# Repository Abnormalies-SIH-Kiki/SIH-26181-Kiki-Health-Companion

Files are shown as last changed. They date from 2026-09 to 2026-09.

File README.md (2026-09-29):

# Kiki - Your AI Health Companion

**SIH 2026 · PS 26181 · Hardware · MedTech / BioTech / HealthTech**

  

Kiki lives on your desk, learns your routines, and talks to you like a friend who actually remembers things[^memory]. Step outside and the same Kiki comes with you, on your wrist.

* **Looks after you** – medicines, schedule, heart rate, sleep.
* **Keeps you in the loop** – reads your WhatsApp, replies for you, brings you news worth hearing.
* **Your yoga instructor** – it watches through the camera, so "I did it" doesn't count.
* **Actually good company** – memory, personality, a bit of humour.

One Kiki across your desk, wrist, and phone — keeping your heart rate, sleep, falls, and surroundings in one place.

## Table of Contents

- [Project Information](#project-information)
- [Problem Statement](#problem-statement)
- [Proposed Solution](#proposed-solution)
- [Key Features](#key-features-mapped-to-problem-statement)
- [Impact](#impact)
- [Hardware and Software](#hardware-and-software)
- [Architecture](#architecture)
- [Run It](#run-it)
- [Code and Build Files](#code-and-build-files)
- [What's Left](#whats-left)
- [Future Scope](#future-scope)

---
<p align="center">
  <h3>✨ 🌟 Kiki Health Companion — Demo Video 🌟 ✨</h3>
  <a href="https://www.youtube.com/watch?v=SXq7fLjbRYM" target="_blank">
    
  </a>
  <br /><br />
  <a href="submission/SIH26181_Team_Abnormalies_Presentation.pdf">
    
  </a>
  <a href="https://drive.google.com/file/d/19Gz7P0E8064CH7wUCHbpV1ZqjmQZaEzY/view" target="_blank">
    
  </a>
</p>

## Project Information

- **Project Title:** Kiki Health Companion
- **PS ID:** 26181
- **PS Title:** A secure, AI-powered Personal Health Companion that delivers real-time, privacy-preserving health monitoring and early warning capabilities, helping individuals recognize health risks before they become emergencies. The solution should improve resilience during heat waves, floods, pollution events, and other disasters common in India while enabling continuous health support through on-device intelligence.
- **Category:** Hardware
- **Theme:** MedTech / BioTech / HealthTech
- **Team:**  Team Abnormalies, NSUT
  - Suyash Srivastava — Hardware & CAD Design
  - Vaibhav Arora — Systems Architecture, AI & Voice Pipeline
  - Aditi Sharma — Backend Engineering & Database 
  - Chirag Goel — Technical Research, Pitch & Video Production
  - Aniket Sharma — Frontend Development & UI/UX Lead 
  - Aavya — Documentation, Web UI & Testing

## Problem Statement

India faces recurring health crises during heat waves, floods, pollution events, and disease outbreaks. Vulnerable groups — elderly, outdoor workers, chronic patients — lack continuous health monitoring that works offline. The problem demands a secure, AI-powered Personal Health Companion that:

* **Talks like it cares** — multilingual, voice-first, for people who won't open an app and can't always read one. A smartwatch hands you numbers and walks away; Kiki answers in about a second, remembers you, and asks how you're doing.
* **Monitors heart rate, SpO₂, activity, sleep, and environmental conditions**
* **Detects anomalies on-device** (heat stress, dehydration, falls, respiratory distress)
* **Provides actionable alerts and emergency assistance**

Kiki directly addresses all of these.

## Proposed Solution

Kiki is a desktop companion and a wearable built around the same idea. The desktop stays in the room and handles conversation, reminders, measures ambient temperature/pressure and camera-based activity checks. The wearable goes with the person and handles steps, on-demand heart rate, and possible falls.

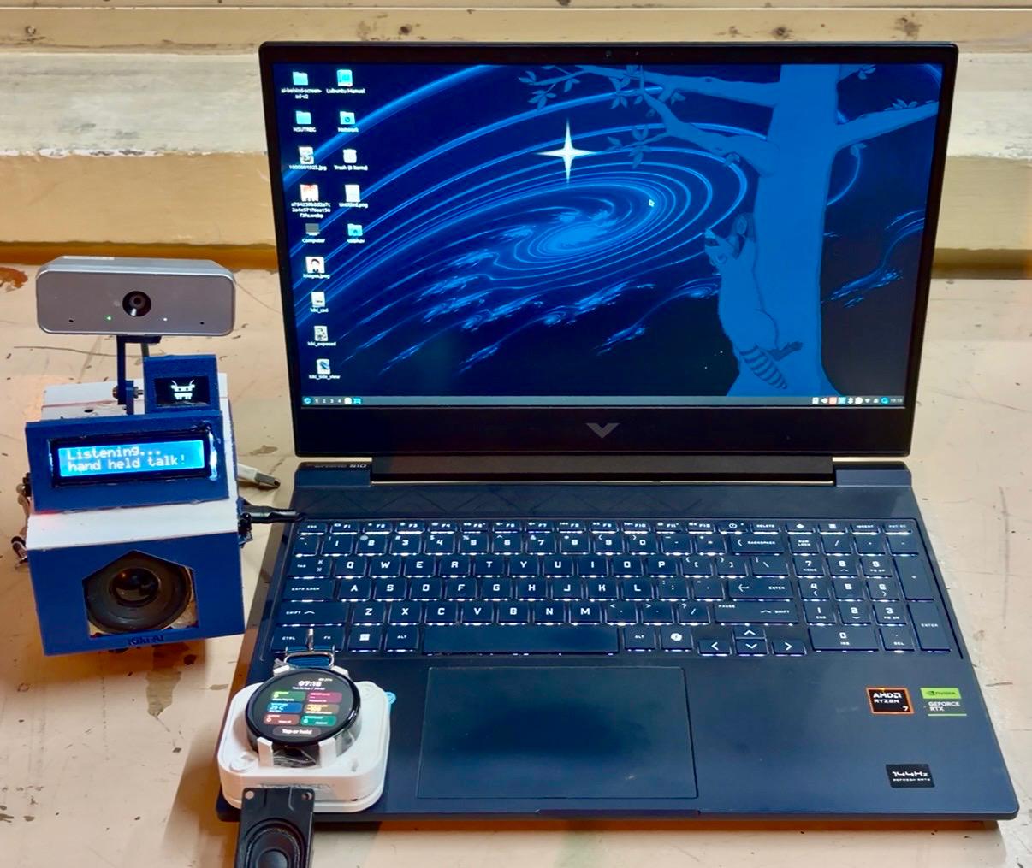
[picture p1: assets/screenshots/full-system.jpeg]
Desktop and wearable health companion and laptop


A health reminder is more useful when it fits the person's day. Kiki keeps routines and recent observations together, so someone can talk through a reminder or an exercise instead of working through an app. Voice interaction supports English and Hindi.

The desktop has a camera for activity detection, face recognition, and exercise checks. The wearable uses wrist motion, with fall detection running in firmware. If it detects a possible fall, it gives the wearer time to respond before requesting a family alert through the gateway.

Both devices use a laptop for speech recognition, speech generation, and the local conversation model. Some reasoning runs through cloud services. Local speech processing and firmware fall detection don't need internet, but the devices still need access to the laptop for conversation. Weather updates, cloud agents, and WhatsApp/email alerts need connectivity.

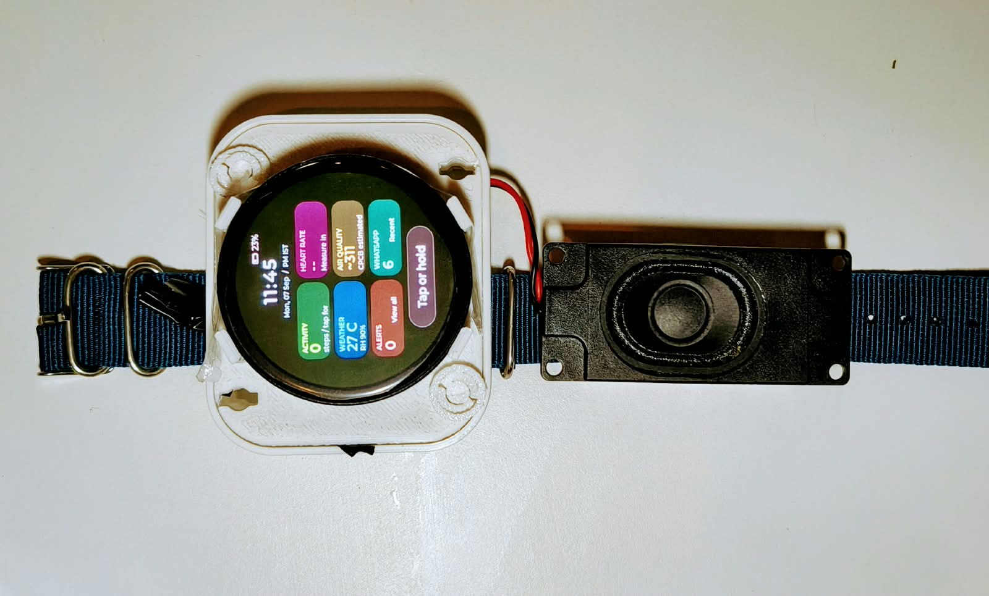
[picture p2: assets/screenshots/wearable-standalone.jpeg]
Real prototype - wearable

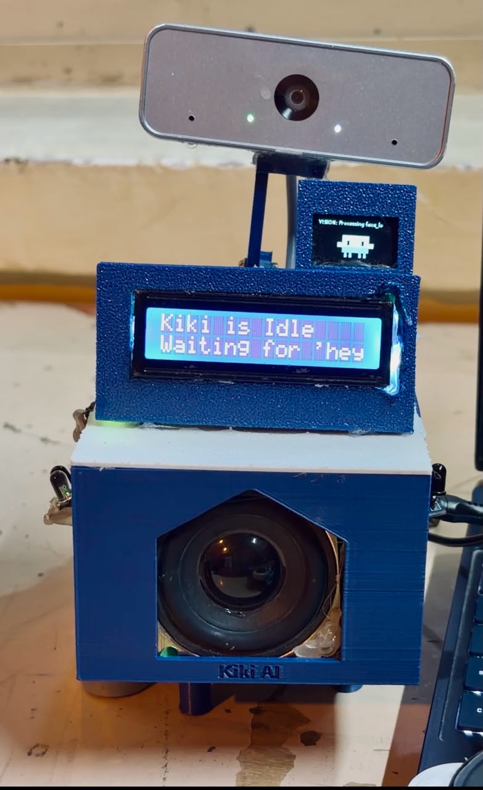
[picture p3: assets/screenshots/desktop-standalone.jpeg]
Real prototype- desktop

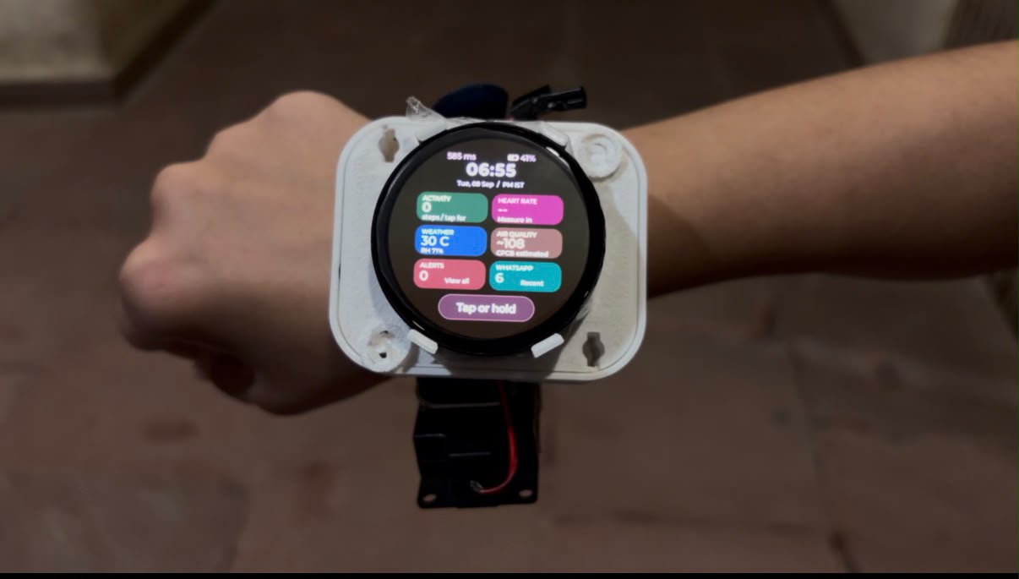
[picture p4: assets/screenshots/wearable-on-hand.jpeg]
Real prototype - werable on hand


## Key Features 
[CAD MODEL](assets/CAD_model/)

Every row below is implemented and running, not planned:

| PS Requirement | Kiki Implementation |
|---|---|
| Continuous health monitoring | On-demand HR/SpO₂, steps, wear detection, activity checks |
| AI-based anomaly detection | Rule-based + ML (edge) for falls, elevated HR, fatigue |
| Disaster-specific alerts | Weather API + estimated AQI, heat index warnings |
| Environmental awareness | Open-Meteo API, stale readings flagged |
| Privacy-preserving edge AI | All raw health data stays on device; only alerts transmitted |
| Emergency assistance | Fall detection → voice check → family alert via gateway |
| Wellness dashboard | Web dashboard + mobile app UI |
| Voice-first accessibility | English and Hindi voice interface, no screen literacy needed |
| Offline capability | Firmware fall detection works without internet |
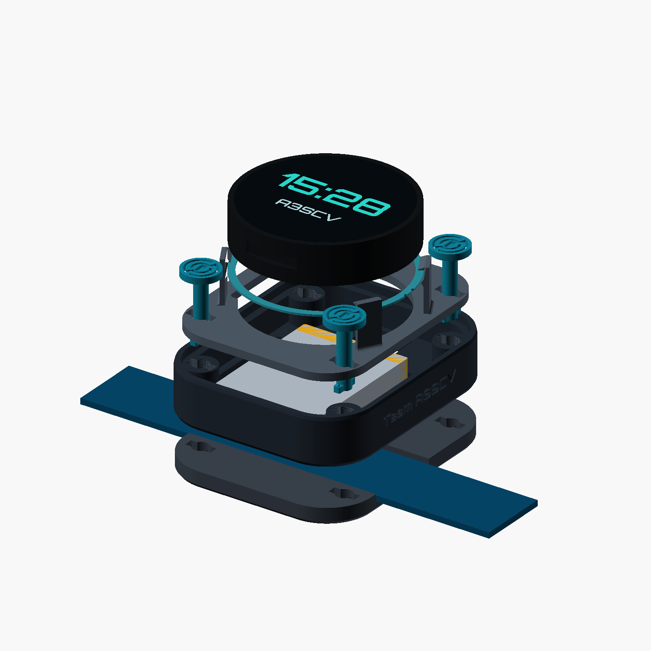
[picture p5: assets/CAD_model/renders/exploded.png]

design_sheet

<table>
  <tr>
    <td width="50%">
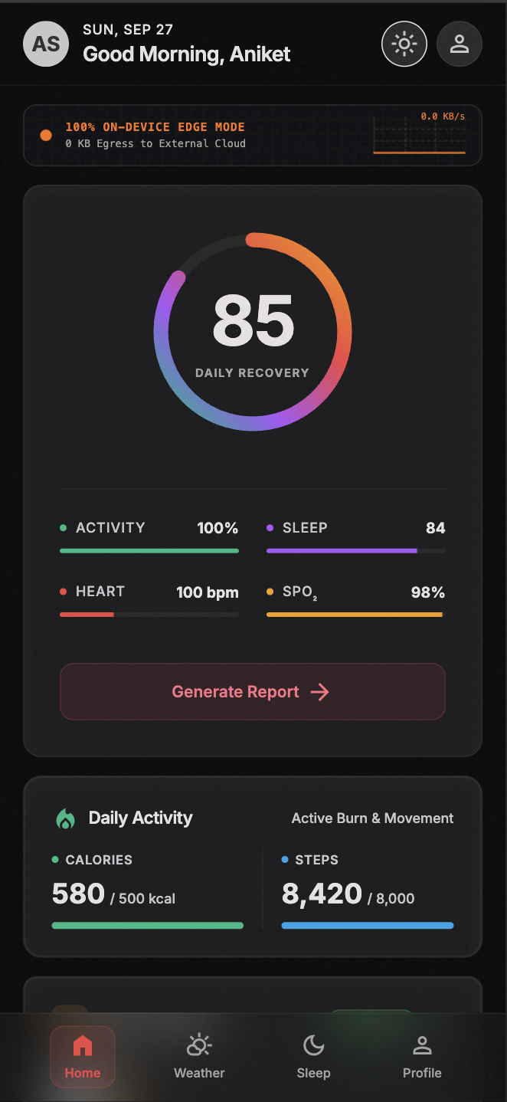
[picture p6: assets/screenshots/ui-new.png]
Live dashboard showing heat risk, blood oxygen and heart rate
      
    </td>
    <td width="50%">
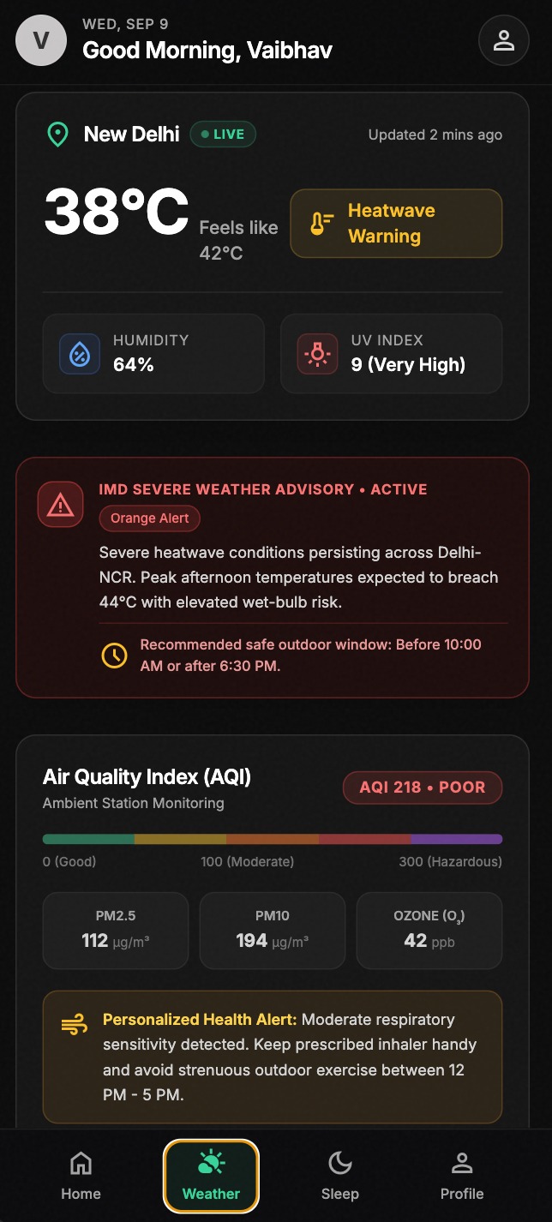
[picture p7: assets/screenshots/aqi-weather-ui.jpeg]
Live dashboard showing AQI and Weather
      
    </td>
  </tr>
  <tr>
    <td width="50%">
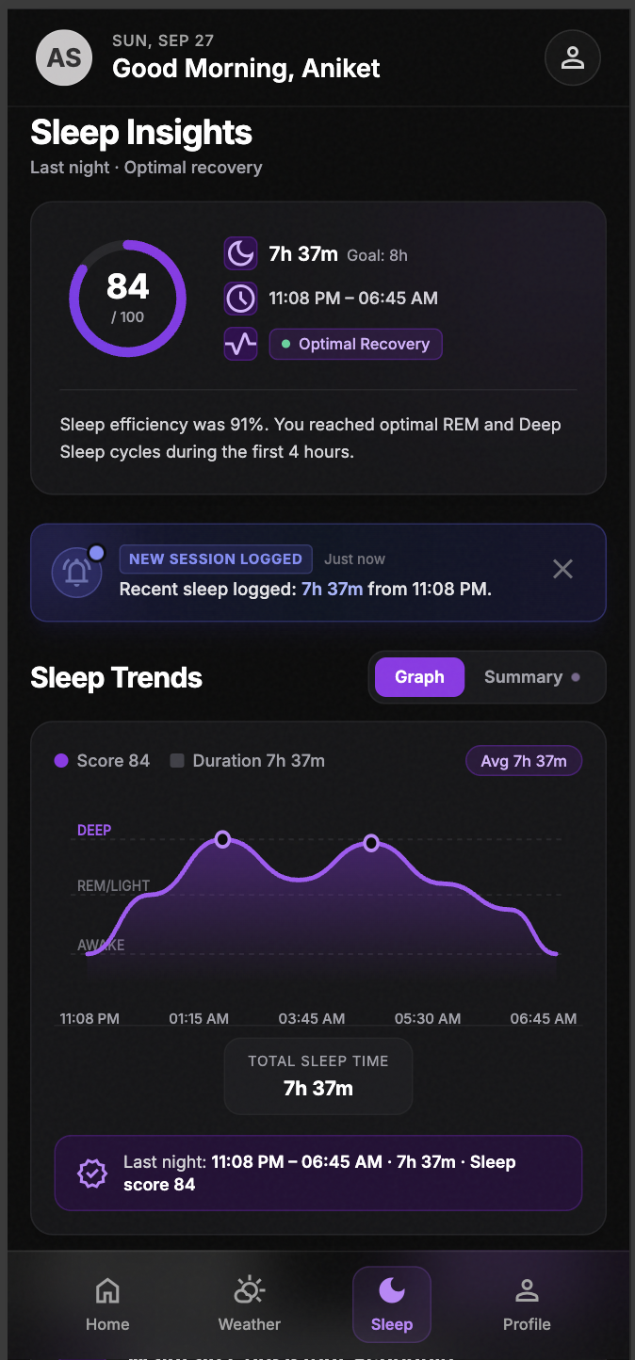
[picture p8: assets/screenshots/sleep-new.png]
Live dashboard showing Sleep Tracking
      
    </td>
    <td width="50%">
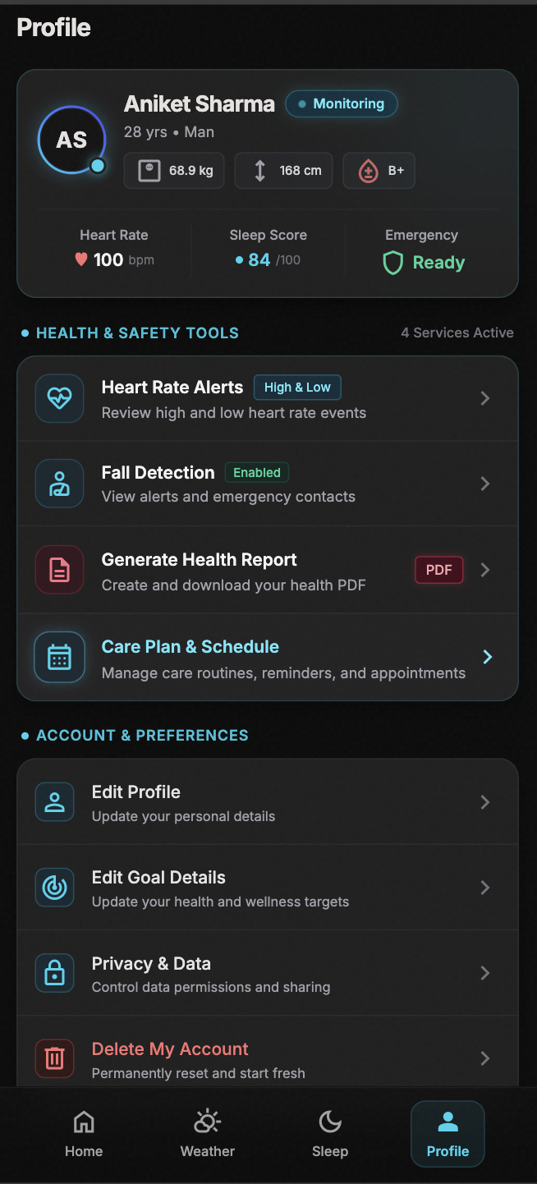
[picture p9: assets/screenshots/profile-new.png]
Live dashboard showing Profile
      
    </td>
  </tr>
</table>

## Impact

Kiki targets exactly the groups the PS names as underserved: elderly citizens, outdoor workers, and people with chronic conditions — the people least likely to have continuous monitoring today, because existing wearables assume connectivity, English literacy, and a willingness to read an app.

- **Social:** voice-first interaction removes the literacy and smartphone-comfort barrier that shuts many people out of existing health apps.
- **Safety:** on-device fall detection and heat/AQI alerts work whether or not the internet does, which matters most exactly when infrastructure is stressed during a disaster.
- **Economic:** built on open-source software and commodity hardware, meaningfully cheaper than commercial continuous-monitoring wearables.
- **Trust:** the system is explicit about what it doesn't know yet rather than presenting unvalidated readings as medical fact — see [What's Left](#whats-left)  

## Hardware and Software

| Part | Current setup |
|---|---|
| Desktop | Raspberry Pi 5, Hailo-8 vision accelerator, USB webcam, 28BYJ-48 stepper, LCD and OLED displays, IR controls, Bluetooth speaker |
| Wearable | Waveshare ESP32-S3-Touch-AMOLED-1.75, MAX30102, QMI8658 IMU, microphones and speaker, 1000 mAh battery |
| Inference laptop | RTX 4060, llama.cpp with gemma-4-26B-A4B, whisper.cpp and OmniVoice |
| Device software | Python desktop module and WebSocket gateway; C++ firmware on ESP-IDF 5.5 |
| Cloud services | Cerebras for multi-step agents (The Exercise Instructor), Gemini for background reasoning |
| Analytics | Python, pandas and NumPy; Next.js/TypeScript dashboard with SQLite; optional TFLite experiment |

## Architecture

```mermaid
graph LR
    subgraph W["Wearable · ESP32-S3"]
        HR["MAX30102<br/>HR + SpO2"]
        IMU["QMI8658 IMU"]
        FALL["Firmware<br/>Fall Detection"]
        HR --> FALL
        IMU --> FALL
    end

    subgraph D["Desktop · Raspberry Pi 5"]
        CAM["Camera + Hailo-8"]
        ENV["BMP280 + Weather API"]
        MOD["Desktop Module<br/>(Python)"]
        CAM --> MOD
        ENV --> MOD
    end

    subgraph G["Gateway · Laptop"]
        WS["WebSocket Server"]
        LLM["LLM<br/>gemma-4-26B"]
        SPEECH["Whisper STT<br/>OmniVoice TTS"]
        RULES["Rule Engine<br/>Anomaly Detection"]
        WS --> LLM
        WS --> SPEECH
        WS --> RULES
    end

    FALL -->|Wi-Fi| WS
    MOD -->|Tailscale| WS
    RULES --> VOICE["Kiki Voice Alert<br/>EN + HI"]
    RULES --> ALERT["WhatsApp /<br/>Email Alert"]
    WS --> DASH[("SQLite +<br/>Dashboard")]
```

Data flows left to right: the wearable streams vitals and fall events over Wi-Fi, the desktop sends camera and environmental context over Tailscale, and the gateway performs reasoning. Alerts and voice output flow back to the user and caregivers, while the dashboard reads from local storage.

See [docs/architecture.md](docs/architecture.md) for the detailed data flow and [docs/ENGINEERING.md](docs/ENGINEERING.md) for the full technical notes.

## Run It

These commands start from the repository root, in separate terminals for each component. You'll need the hardware for the full demo, Python 3.12+ for the gateway, and ESP-IDF 5.5 for firmware builds. The model, speech, and hardware services need to be set up separately; installing the Python packages doesn't start them.

There's no single root `requirements.txt` — this is a multi-component system (desktop, gateway, firmware), so each component manages its own dependencies. Each is installed separately below.

**Desktop, on the Pi**

```bash
cd src/desktop-module
python3 -m venv .venv
source .venv/bin/activate
pip install -r requirements.txt
cp .env.example .env
cp tools_and_config/config.example.json tools_and_config/config.json
# Set API keys and update service addresses for your machines.
python main.py
```

**Gateway, on the laptop**

```bash
cd src/wearable
python3.12 -m venv .venv
source .venv/bin/activate
pip install -e gateway
cp gateway.env.example gateway.env
# Set the gateway token, inference URLs and shared care-plan paths.
./scripts/run_gateway.sh
```

**Wearable firmware**, from a shell with ESP-IDF loaded:

```bash
cd src/wearable/firmware
idf.py set-target esp32s3
idf.py menuconfig
# Set Wi-Fi, gateway address and the matching gateway token.
idf.py build
idf.py -p /dev/ttyACM0 flash monitor
```

Change the serial port if your board appears elsewhere. More deployment details are in [docs/wearable/DEPLOY.md](docs/wearable/DEPLOY.md). Keep credentials in your local configuration files.

## Code and Build Files

| Location | Contents |
|---|---|
| [src/](src/README.md) | Code map, test commands and analytics setup |
| [docs/architecture.md](docs/architecture.md) | High-level system diagram |
| [docs/ENGINEERING.md](docs/ENGINEERING.md) | Technical notes and known limits |
| [docs/data/](docs/data/) | Captured system output and analytics sample |
| [assets/hardware/](assets/hardware/) | Build photos |
| [assets/circuit_diagram/](assets/circuit_diagram/) | Wiring diagrams and Fritzing sources |
| [assets/CAD_model/](assets/CAD_model/) | Enclosure source, renders and print files |
| [submission/PRESENTATION.md](submission/PRESENTATION.md) | Presentation details and links |
| [submission/SIH26181_Team_Abnormalies_Presentation.pdf](submission/SIH26181_Team_Abnormalies_Presentation.pdf) | Final SIH idea submission deck (also on [Google Drive](https://drive.google.com/file/d/19Gz7P0E8064CH7wUCHbpV1ZqjmQZaEzY/view)) |
| [submission/DEMO.md](submission/DEMO.md) | Demo details |

## What's Left

The MAX30102's SpO₂ estimate is uncalibrated and isn't treated as a health reading, even though an early prototype photo shows it on the display.

## Future Scope

- Continuous wrist SpO₂ with improved motion artifact removal
- Body temperature sensor integration (non-contact)
- GPS location for outdoor emergency response
- Automatic sleep quality analysis
- Multi-language support beyond Hindi/English
- Clinical validation and CDSCO certification

[^memory]: Kiki doesn't dump transcripts into context. Durable facts about you are saved
    deliberately to a knowledge base, and recall searches across the journal, the knowledge
    base and past conversations rather than one store.
    See [memory_search](src/desktop-module/Codestructure.md#memory).

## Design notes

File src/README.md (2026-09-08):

# Source code

The code is split between the desktop, wearable and analytics work. These are snapshots of the source repositories. Their earlier Git history isn't included because it contained credentials.

| Path | Runs on | Purpose |
|---|---|---|
| `desktop-module/` | Raspberry Pi 5 | Conversation, tools, camera and Hailo vision, care sessions, displays and stepper control |
| `wearable/firmware/` | ESP32-S3 | Audio, watch UI, sensors, steps and fall detection; C++ on ESP-IDF 5.5 |
| `wearable/gateway/` | Laptop | Voice processing, care sessions and wearable telemetry |
| `wearable/scripts/` | Laptop | Build, flash and run helpers |
| `health-analytics/` | Laptop | Trend pipeline and caregiver dashboard |

The gateway still imports a few modules from `wearable/gateway/legacy_kiki/`, a bundled older copy of the desktop code.

## Analytics

`health-analytics/` is included with the author's permission from AditiS721/SIH-Abnormalies-Software, branch `DevAniket`.

Its `src/` folder contains the rule-based pipeline: baselines, anomalies, daily summaries, trends and risk scores. It currently runs on generated data. `vitality-app/` is the Next.js dashboard with its own SQLite database; connecting these to live wearable telemetry is still pending.

`src/train_tflite_model.py` and `esp32_export/` are a separate model experiment. They don't drive the watch's fall alerts. That detector lives in `wearable/firmware/main/kiki_fall_detector.hpp`.

## Local setup and checks

Start with the [root README](../README.md) for device setup. Each test command below starts from `src/`, with that component's environment active and its test dependencies installed:

```bash
# Desktop
cd desktop-module
PYTHONPATH=. python -m pytest -q
```

```bash
# Gateway
cd wearable/gateway
pip install -e '.[test]'
PYTHONPATH=. python -m pytest -q
```

The recorded run on 8 September 2026 had 1,101 desktop tests and 538 gateway tests passing. These suites don't need hardware or running inference services.

Analytics has an end-to-end script instead of a test suite. From `src/`:

```bash
cd health-analytics
pip install -r requirements.txt
python src/pipeline.py
```

It writes generated results to `data/`. A saved example is in [docs/data/analytics_pipeline_output.json](../docs/data/analytics_pipeline_output.json).

## What's excluded

Local credentials, runtime conversations, recordings, face data, contact details and build output aren't included. Use the example configuration files to create your own setup; update service addresses as well as keys. Firmware binaries are excluded because they contain the compiled gateway token.

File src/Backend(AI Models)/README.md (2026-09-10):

# Personal Health Telemetry & ESP32 Edge-AI System

A wearable health-telemetry and edge-AI pipeline for ESP32 (QMI8658 IMU + MAX30102 PPG).

**What it does:**
- ❤️ Detects heart-rate and SpO₂ anomalies against a personal, per-activity baseline
- 🚶 Classifies activity (Resting / Inactive / Walking / Running / Transition) via a Decision Tree
- ⚠️ Detects falls on-device using a quantized 1D CNN (TFLite Micro) with a post-fall confirmation state machine
- 📊 Combines everything into an explainable risk score, output as structured JSON once per second

---

## 🛠 Tech at a glance

| Layer | Tooling |
|---|---|
| Data generation & training | Python (numpy, scikit-learn, TensorFlow) |
| Firmware | C++ (Arduino framework via PlatformIO), TFLite Micro |
| Target hardware | ESP32-WROOM class boards |

---

## Pipeline

Runs once per second, fully on-device:

```mermaid
flowchart TD
    A["Dummy sensors<br/>IMU 50Hz + vitals 1Hz"] --> B["Feature extraction<br/>1-second window stats"]
    B --> C["Activity classifier<br/>Decision Tree, 5 states"]
    B --> D["Fall detector<br/>CNN + confirmation FSM"]
    C --> E["Baseline check<br/>Per-activity HR/SpO2"]
    E --> F["Risk engine<br/>Score + JSON build"]
    D --> F
    F --> G["Serial output<br/>One JSON line/sec"]
```

1. **Sensors** — 50Hz IMU (accel+gyro), 1Hz vitals (HR+SpO₂). Synthetic now (`dummy_sensor.h`); swap for real I2C reads later, no downstream changes needed.
2. **Feature extraction** — each 1s IMU window collapses to 6 numbers (magnitude mean/variance/peak, movement intensity) for the Decision Tree.
3. **Activity classifier** — Decision Tree (compiled to C `if/else`) labels Resting/Inactive/Walking/Running/Transition with a confidence score.
4. **Fall detector** — CNN runs on the raw 50Hz window (needs the actual sequence, not collapsed stats). A confirmation FSM requires ~3s of post-impact stillness before flagging, to reject jumps/drops.
5. **Baseline check** — HR/SpO₂ compared to a personal baseline *per current activity*, at two timescales (fast for spikes, slow for drift).
6. **Risk engine** — combines anomaly + fall flags into a 0–100 score with reasons.
7. **Serial output** — snapshot serializes to JSON (ArduinoJson), prints over USB.

## Why these three models

Each task got the cheapest model that fits its structure — not the most sophisticated one available.

| Task | Model | Why it fits | Rejected alternatives |
|---|---|---|---|
| HR/SpO₂ anomaly | Rule-based, dual-timescale baseline | Personal deviation detection; ~16B RAM, explainable z-scores, no cold-start data needed | PCA/Mahalanobis, Autoencoder — need a "normal" data corpus first, opaque output |
| Activity classification | Decision Tree | Nonlinear but simple boundaries; <1KB flash, <1ms inference, auditable branches | Logistic Regression, MLP — no accuracy gain for the added cost/opacity |
| Fall detection | Tiny 1D CNN (INT8) | Only task needing temporal pattern — sequence order (dip → spike → stillness) is the signal | Threshold rule, Decision Tree on stats — miss event order, false-positive prone |
| Excluded | — | — | Mahalanobis, full Autoencoder, general MLP — none fit any task better, all cost more RAM/flash |

### Resource footprint

| Component | RAM | Flash | Inference |
|---|---|---|---|
| Rule-based baseline (×2 metrics ×5 activities ×2 timescales) | ~160B | negligible | none (O(1)) |
| Decision Tree | 0 (stack only) | <1KB | <1ms |
| 1D CNN, INT8, TFLite Micro | tens of KB (≈96KB w/ full runtime on real hardware) | ~8KB model + ~40KB runtime | a few ms |

Measured on real ESP32-WROOM (320KB RAM): full pipeline used **29.4% RAM, 40.2% flash**.

---

## Repository structure

```
data_generation/
  generate_dummy_data.py   Synthetic IMU (50Hz) + vitals (1Hz) generator: activities,
                            transitions, falls, hard-negatives (drop/sit/jump/gesture)

training/
  train_decision_tree.py   Extracts features, trains activity Decision Tree,
                            exports compiled C comparisons (activity_tree.h)
  train_cnn.py              Trains CNN fall detector, quantizes INT8, exports TFLite
                            Micro C array + norm constants. Stratified train/test split.
  requirements.txt          numpy, pandas, scikit-learn, tensorflow-cpu

firmware/                   PlatformIO project, any ESP32-WROOM class board
  platformio.ini             Build config (Arduino, TFLite Micro, ArduinoJson)
  include/config.h           All tunable thresholds/constants
  include/dummy_sensor.h     On-device synthetic sensor generator
  include/motion_gate.h      Rejects PPG samples during high-motion windows
  include/baseline.h         Dual-timescale Welford/EMA personal baseline
  include/fall_detector.h    TFLite Micro CNN wrapper + confirmation FSM
  include/risk_engine.h      Risk score + JSON schema
  include/activity_tree.h    Generated (checked in from a demo run)
  include/fall_model_data.h  Generated (checked in from a demo run)
  include/fall_model_norm.h  Generated — CNN input normalization constants
  src/baseline.cpp           Baseline engine
  src/fall_detector.cpp      CNN inference + confirmation FSM
  src/risk_engine.cpp        JSON serialization (ArduinoJson)
  src/main.cpp               Wires the 50Hz/1Hz pipeline together

models/                     Regenerated activity_tree.h / fall_model_* land here
data/                       Generated CSVs land here (gitignored)
```

## Quick start

### 1. Generate data and train

```bash
cd training
pip install -r requirements.txt   # TensorFlow needs Python 3.9-3.12; use a venv if
                                   # your system Python is newer (3.13/3.14 lack TF wheels)
python ../data_generation/generate_dummy_data.py --minutes 3000 --seed 21 --out ../data
python train_decision_tree.py --imu ../data/imu_50hz.csv --out ../models
python train_cnn.py --imu ../data/imu_50hz.csv --out ../models --epochs 25
```

`--minutes 3000` targets ~50+ Fall segments (falls are ~3% chance per state transition by design). Check the printed `Train falls: X  Test falls: Y`; regenerate with more minutes if `Y` is under ~5.

```bash
cp ../models/activity_tree.h ../models/fall_model_data.h ../models/fall_model_norm.h ../firmware/include/
```

(Repo ships with headers from a prior run, so `firmware/` builds out of the box — overwrite anytime for a fresh model.)

### 2. Build and flash

```bash
cd firmware
pio run
pio run -t upload
pio device monitor -b 115200
```

Boots into dummy-sensor mode, prints one JSON line/sec:
```json
{"user_id":"user_001","summary":{"avg_hr":68.06,"avg_spo2":98.08},"activity":{"state":"resting","confidence":1},"anomalies":{"heart_rate":false,"spo2":false,"trend":false},"fall_detection":{"detected":false},"risk":{"score":0,"level":"low"},"reasons":[]}
```

## Notes

- `firmware/` targets generic `esp32dev` in `platformio.ini` — change `board =` for your hardware. Real test hardware reported 320KB RAM (not all ESP32-WROOM variants have 520KB); check your own `pio run` output.
- `TENSOR_ARENA_SIZE` in `config.h` (60KB) is a starting estimate — measure real usage via `interpreter->arena_used_bytes()` and adjust.
- The activity name lookup in `main.cpp` assumes the checked-in `activity_tree.h`'s enum order. Verify it after retraining with a different label set.

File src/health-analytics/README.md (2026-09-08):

# Personal Health Telemetry Prototype

A rule-based-first health telemetry pipeline: dummy wearable data -> personal
baseline -> anomaly detection -> daily summaries -> trend detection ->
rule-based risk score -> structured JSON for **Kiki** to consume. A tiny
optional TFLite Micro model for ESP32 is included, with findings on where it
actually helps.

Guiding principle: **a baseline/anomaly system that reliably works in a demo
beats an unverifiable "AI predicts disease" story.** Nothing here claims to
diagnose anything; it flags deviations from *this specific person's* own
patterns and explains why in plain language.

## Quick start

```bash
cd telemetry_system
pip install -r requirements.txt
python3 src/pipeline.py          # generates data, runs the full rule-based pipeline
python3 src/train_tflite_model.py  # optional: trains + exports the ESP32 model
```

Final output for Kiki: `data/kiki_insights.json` (one structured object per user/day).

## Pipeline stages

| Stage | File | What it does |
|---|---|---|
| 1. Ingest | `generate_dummy_data.py` | Simulates minute-level HR/steps/activity with circadian rhythm + injected, labelled anomalies (for validation only -- a real device feed replaces this file) |
| 2. Baseline | `baseline.py` | Per-user, per-hour-of-day, per-activity-level mean/std HR; per-user average daily steps |
| 3. Deviation detection | `anomaly_detection.py` | Z-score vs. baseline + persistence filter (kills single-sample noise); separate "unexpected inactivity" rule for gaps HR alone misses |
| 4. Daily summary | `daily_summary.py` | Steps, active minutes, resting/avg/max/min HR, anomaly-minute count per user/day |
| 5. Trend detection | `trend_detection.py` | Rolling linear-regression slope over 7 days, classified rising/falling/stable relative to the metric's own scale |
| 6. Risk score | `risk_score.py` | Sums named, capped point contributions (anomaly load, HR trend, activity trend) into a 0-100 score + low/moderate/high band, with a plain-English reason list |
| 7. Insights | `insights.py` | Merges everything into the Kiki-facing JSON contract (schema below) |

Run any file standalone against the CSVs it depends on, or run all of them via `pipeline.py`.

### Validating detection against ground truth

`generate_dummy_data.py` labels its injected anomalies (`is_injected_anomaly`).
`anomaly_detection.py` prints a TP/FP/FN comparison against that ground truth
on every run -- current tuning catches roughly 85% of injected events with a
modest false-positive rate. This is a debugging aid only; it disappears once
real device data replaces the simulator (real data has no ground-truth labels).

## Kiki insight JSON schema

```json
{
  "user_id": "user_001",
  "date": "2026-01-21",
  "summary": {"total_steps": 28332, "active_minutes": 506, "avg_hr": 75.4,
              "resting_hr_est": 65.8, "max_hr": 137.0, "min_hr": 54.2},
  "baseline_comparison": {"resting_hr_vs_7d_avg": 0.3, "steps_vs_7d_avg": -1557.0},
  "anomalies": {"count_today": 17, "recent_examples": [{"timestamp": "...", "heart_rate": 136.2, "deviation_type": "elevated"}]},
  "trends": {"resting_hr_trend": "stable", "steps_trend": "stable", "active_minutes_trend": "stable"},
  "risk": {"score": 34.0, "level": "moderate", "reasons": ["17 confirmed anomaly minute(s) today (+34)"]},
  "narrative": "Risk level today: moderate (score 34/100). Contributing factors: ..."
}
```

Kiki can render `narrative` directly, or use the structured fields to decide
tone/follow-up questions without ever touching raw telemetry.

## Where TensorFlow Lite / Edge AI actually helps (investigation findings)

This was tested directly, not assumed -- `train_tflite_model.py` trains a
tiny (4->4->2->4->4) dense autoencoder on (heart_rate, steps, sin(hour),
cos(hour)) to catch *joint* pattern anomalies a single-variable z-score can
miss, then quantizes it to int8 for TFLite Micro (~3.2 KB model file).

**Result on this dummy dataset: the rule-based detector outperformed the
autoencoder.** Rule-based caught ~420/492 injected anomalies with 181 false
positives; the autoencoder caught ~123/492 with 600 false positives, using
the same 99th-percentile-of-normal threshold approach. Conclusion for this
prototype:

- **Keep rule-based for the core detection path.** Z-score + persistence is
  cheap, interpretable, tunable by a human without retraining, and simply
  won here on the data we could construct. This should stay the primary
  signal reported to Kiki and shown in any demo.
- **A learned model is worth revisiting once real (not simulated) data
  exists**, specifically for multivariate/joint patterns that are hard to
  hand-write as rules -- e.g. HR-variability-derived stress patterns, or
  combining HR with accelerometer-derived motion signatures. Dummy data is
  too clean/well-behaved for an autoencoder to find structure rules don't
  already capture; this needs real physiological noise to evaluate properly.
- **Genuine edge-AI candidates for a v2**, once real datasets are in hand:
  - Arrhythmia-pattern classification from raw PPG/ECG waveforms (this is
    where CNNs/1D-conv nets meaningfully beat hand rules -- see MIT-BIH /
    PPG-DaLiA below).
  - Activity/gesture classification from raw accelerometer data (a classic,
    well-proven TFLite Micro use case on ESP32-class hardware).
  - Sleep-stage estimation from combined HR + motion.
- **What should stay off an ESP32 regardless:** anything that needs a large
  labelled clinical dataset to be trustworthy (e.g. actual disease
  prediction). That belongs in a cloud-side model with proper validation,
  not a microcontroller demo.

The ESP32 export (`esp32_export/anomaly_inference/`, containing
`anomaly_inference.ino` + `model_data.h`) is provided as a working example of
the *mechanics* (train -> quantize -> C header -> TFLite Micro inference
loop) so the path is ready when a task that actually needs it comes along,
per the findings above. The sketch targets the official TFLite Micro Arduino
library's `AllOpsResolver` + `ErrorReporter` API pattern -- if you install a
different TFLite Micro port, the interpreter setup code in `setup()` may
need adjusting to match that library's own bundled example sketch (the model
bytes in `model_data.h` itself don't change either way).

## Public / government datasets for future model development

| Dataset | Source | Useful for |
|---|---|---|
| MIT-BIH Arrhythmia Database | PhysioNet (physionet.org) | ECG arrhythmia classification, gold-standard benchmark |
| PPG-DaLiA | PhysioNet / UCI | PPG-based HR estimation during real daily activities (closest match to a wrist wearable) |
| WESAD (Wearable Stress and Affect Detection) | Uni Siegen / PhysioNet | Stress detection from wearable HR/EDA/motion |
| MIMIC-III / MIMIC-IV Waveform | PhysioNet (credentialed access) | ICU-grade vitals, HR/SpO2 time series at scale |
| Apple Heart Study / Stanford data releases | Stanford Medicine | Large-scale wearable-detected arrhythmia population data |
| UK Biobank accelerometer data | UK Biobank (application required) | Large-N free-living activity data for population activity baselines |
| NHANES | CDC | Population-level HR/activity/health baseline statistics, useful for sanity-checking "normal" ranges by age/sex |
| Fitbit/Apple Watch open research datasets (e.g. via Kaggle "Fitbit Fitness Tracker Data") | Kaggle (community-curated, not government) | Cheap, fast prototyping of daily-summary-level logic before touching clinical data |

PhysioNet is the strongest starting point: most of the above HR/PPG/ECG
sets are hosted or indexed there under a consistent access model, and several
(MIT-BIH, PPG-DaLiA, WESAD) are openly downloadable without a credentialing
process, unlike MIMIC.

## File layout

```
telemetry_system/
  data/                    generated CSV/JSON at each pipeline stage
  models/                  trained .tflite model + feature_scaler.json
  esp32_export/
    anomaly_inference/     the Arduino sketch folder (anomaly_inference.ino + model_data.h)
  src/
    generate_dummy_data.py
    baseline.py
    anomaly_detection.py
    daily_summary.py
    trend_detection.py
    risk_score.py
    insights.py
    pipeline.py            runs stages 1-7 in order
    train_tflite_model.py  optional, separate from the core pipeline
  requirements.txt
  README.md
```

## Honest limitations of this prototype

- Dummy data only -- no real device has fed this pipeline yet. Thresholds
  (z=2.2, persistence=2, risk-score weights) are reasonable starting points,
  not clinically validated.
- Risk score is additive and capped, not probabilistic -- treat the number
  as a triage signal, not a calibrated probability of anything.
- "Resting HR" is estimated from sedentary-minute averages, not a proper
  sleep-HR estimate (would need sleep-stage detection to do that well).
- None of this should be presented as diagnosing a condition. It flags
  deviation from a person's own baseline and says so explicitly.

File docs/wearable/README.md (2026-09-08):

# Kiki ESP32-S3

This is an isolated implementation of Kiki for the Waveshare
ESP32-S3-Touch-AMOLED-1.75. It does not modify the existing `KikiFast` tree or
the laptop inference manager.

The latency-critical split is deliberate:

- ESP32: microphones, speaker, touch AMOLED, Wi-Fi, playback buffering and UI.
- Laptop gateway: RNNoise, Silero VAD, speculative Whisper, the existing Kiki
  conversation/tool/background runtime, llama.cpp and omnivoice streaming.

See `docs/ARCHITECTURE.md` and `docs/DEPLOY.md` for the measured rationale and
deployment instructions.

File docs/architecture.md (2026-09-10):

# System Architecture

## High-level flow

```text
Wearable (ESP32-S3)              Desktop (Raspberry Pi 5)
  MAX30102, QMI8658 IMU            Camera, mics, speaker, displays
        |                                   |
        | firmware: fall/step detection     | camera activity checks,
        | (works with zero connectivity)    | face recognition, reminders
        |                                   |
        +---------------+-------------------+
                         |
                         v
              Gateway (laptop, WebSocket)
                         |
        +----------------+-----------------+
        |                                  |
        v                                  v
  Local inference                   Cloud services
  (llama.cpp, whisper.cpp,          (Cerebras, Gemini)
   OmniVoice — no internet          (background reasoning,
   needed for speech)                multi-step agents)
        |                                  |
        +----------------+-----------------+
                         |
                         v
        Voice response, WhatsApp/email alert,
        Web dashboard (Next.js + SQLite)
```

## Components

### Wearable (ESP32-S3-Touch-AMOLED-1.75)
Runs C++ firmware on ESP-IDF 5.5. Handles on-demand heart rate/SpO₂ (MAX30102), step counting and fall detection (QMI8658 IMU). Fall detection and step counting run entirely on-device — no connectivity required for this layer.

### Desktop (Raspberry Pi 5)
Runs the Python desktop module. Handles voice conversation, camera-based activity detection and face recognition (via Hailo-8 accelerator), reminders, and the shared care plan.

### Gateway (laptop)
A WebSocket service that both devices connect to. Hosts local LLM inference (llama.cpp with gemma-4-26B-A4B), speech-to-text (whisper.cpp) and text-to-speech (OmniVoice). The devices reach the laptop over Tailscale.

### Cloud services
Cerebras and Gemini handle background/multi-step reasoning that doesn't need to be instant. Not required for core safety features (fall detection, offline alerts still work without them).

### Analytics dashboard
Next.js/TypeScript frontend backed by SQLite, built from Python/pandas processing of the captured sensor data. Surfaces heat index, AQI risk, HR/SpO₂ trends and sleep insights.

## For full technical detail

This file is deliberately a high-level map. For wiring, audio pipeline details, latency numbers, and the specific failures that shaped these design decisions, see [ENGINEERING.md](ENGINEERING.md).

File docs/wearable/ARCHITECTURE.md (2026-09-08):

# Route 1 architecture

The ESP32 is a real-time audio/display endpoint. The laptop remains the compute
and state authority. This is the only route that preserves the current model
quality: the board has 8 MB PSRAM and 16 MB flash, while Kiki's LLM, Whisper,
OmniVoice and Python tool runtime are orders of magnitude larger. The board's
466 x 466 AMOLED, capacitive touch, ES7210 microphone input and ES8311 speaker
output are used directly.

```text
microphones -> ESP32 I2S (48 kHz, 10 ms frames)
            -> persistent WebSocket over 2.4 GHz Wi-Fi
            -> laptop RNNoise -> 48/16 kHz FIR -> Silero VAD
                    | 240 ms silence: speculative Whisper
                    | 600 ms silence: conservative commit
                    v
               existing Kiki prompt + memory + tools + llama.cpp KV cache
                    v
               sentence stream -> OmniVoice PCM -> 24/48 kHz resampler
                    v
               same WebSocket -> ESP32 jitter buffer -> ES8311 speaker
```

## Why VAD stays on the laptop

Silero is still local: it moved from the Pi to a machine on the same LAN, not to
an internet service. Audio is sent continuously in 10 ms frames, so VAD sees it
while the user is speaking. The conservative 600 ms endpoint is retained for
transcription quality, but Whisper starts after 240 ms of apparent silence. If
speech resumes, that speculative result is cancelled. In the common case most
of STT is therefore hidden inside the remaining endpoint wait.

Running a different tiny VAD on the ESP32 would save roughly one LAN frame but
would change endpoint decisions and can cost hundreds of milliseconds through
false endpoints. The continuous-stream design preserves the production
RNNoise/Silero behavior and makes network setup happen at boot rather than on a
turn's critical path.

## Latency controls

- Wi-Fi modem power saving is disabled.
- The WebSocket is persistent, has compression disabled, and carries binary PCM.
- Capture and playback both use 48 kHz so the board never reconfigures its shared
  audio clocks during a turn.
- A 640 ms bounded microphone queue isolates I2S from Wi-Fi jitter; gaps are
  reported rather than silently shifting audio.
- RNNoise, FIR decimation, wake-word inference and Silero run incrementally.
- Partial ASR warms the llama.cpp prefix while the user is still speaking.
- TTS begins on the first eager sentence and streams PCM; it never waits for the
  full answer.
- The laptop's existing `--prefill-after-response` and KV-cache contract remain
  in use.
- Background workers, idle mind, WhatsApp and web UI initialize outside the
  connection and speech hot paths.

## Feature placement

| Feature | Placement |
|---|---|
| AMOLED face/expression tags, state, transcript, touch wake/cancel | ESP32 |
| I2S capture/playback, volume, bounded jitter queues | ESP32 |
| RNNoise, near-field gate, Silero, wake word | Laptop gateway |
| Whisper, Gemma/llama.cpp, OmniVoice | Existing laptop servers |
| Kiki prompt, memory, modes, tools and KV history | Isolated laptop legacy snapshot |
| Idle mind, ambient buffer, workers, WhatsApp/MCP, web UI | Laptop |
| Music lookup/decoding, liked songs, timers, named voices | Laptop, PCM/effects delivered to ESP32 |

## Deliberately unavailable

Camera-dependent behavior is removed: live vision, face recognition/enrolment,
person tracking, visual greetings and image-based peeping. The copied prompt is
overridden so Kiki does not claim it can see. Pi-only Bluetooth/ALSA output is
also replaced by the board speaker. Physical neck and IR-hand gestures require
their separate controller hardware; on this board, touch supplies wake and
cancel. Nothing else needs to be reduced for flash or RAM because the Python
runtime and models do not run on the microcontroller.

## Failure behavior

If the laptop or LAN is unavailable, the ESP32 remains an offline UI/audio
endpoint and reconnects. It cannot provide an equal-quality offline answer: an
ESP32-scale fallback model would violate the quality requirement. A future
route can add a visibly degraded emergency command set, but it must not be
presented as equivalent Kiki. The isolated runtime's cloud speaking fallback is
disabled, so a failed laptop llama.cpp service fails visibly instead of silently
changing model quality or sending the conversation to a hosted model. Web,
messaging and other explicitly network-backed tools retain their normal APIs.

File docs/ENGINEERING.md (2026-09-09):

# Engineering notes

 Project details and setup commands are in the [README](../README.md); this file keeps the hardware choices, software constraints and debugging notes that are useful when working on it.

## How the system fits together

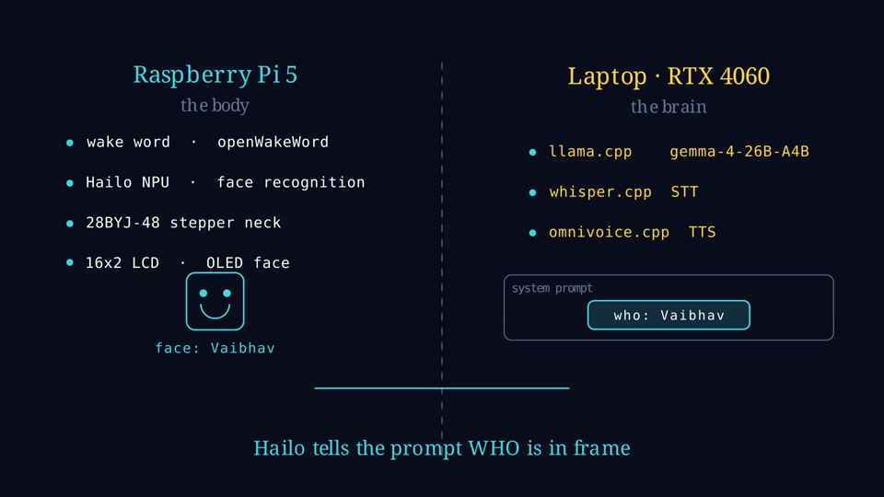
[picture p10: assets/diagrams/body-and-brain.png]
System architecture


The Raspberry Pi 5 handles the desktop's camera, controls, displays and motor. The ESP32-S3 handles the watch. A laptop with an RTX 4060 runs the local model and speech services, with the machines connected through Tailscale.

| Laptop service | Port |
|---|---|
| llama.cpp | 8080 |
| OmniVoice TTS | 8082 |
| whisper.cpp | 5555 |
| Wearable gateway | 8765 |

The local conversational model is `gemma-4-26B-A4B`. It runs with `-np 1`, giving it one inference slot. Foreground conversation gets priority because waiting behind a background generation makes the device feel unresponsive.

Cerebras handles multi-step agent work, while Gemini handles background reasoning. The background process can save context for later conversations, but it can't move the robot or independently send messages. Speech recognition and the ambient buffer stay on our hardware; reasoning over that context can involve a cloud call.

The model's expert offload setting is `--n-cpu-moe 30`. Most expert tensors stay in system memory, keeping the measured VRAM use around 5 GB. The mixture-of-experts model reduces active computation per token, but that alone doesn't make all the weights fit in VRAM.

### Keeping conversation fast

Our live-server prefill test, `tests_llamaserver/test_prefill_e2e.py`, measured **24.0 seconds cold** and **1.26 seconds warm**. These are measurements from our setup, not a promise for every reply.

The difference came from preserving the conversation prefix in llama.cpp's KV cache. Editing an earlier message forces the server to process context again. We had a timestamp in `message[1]` that changed every five minutes; that small edit caused recurring cold starts.

The client now keeps old messages unchanged and stores assistant output exactly as generated, including `<neck:>`, `<oled:>` and `<tool_call>` tags. Warmup happens after the final context is assembled. If another request disturbs the local cache, the foreground conversation needs warming again.

Speech also starts before the whole reply is finished. Each completed sentence goes to TTS while the model generates the next one.

## Hardware

### Desktop

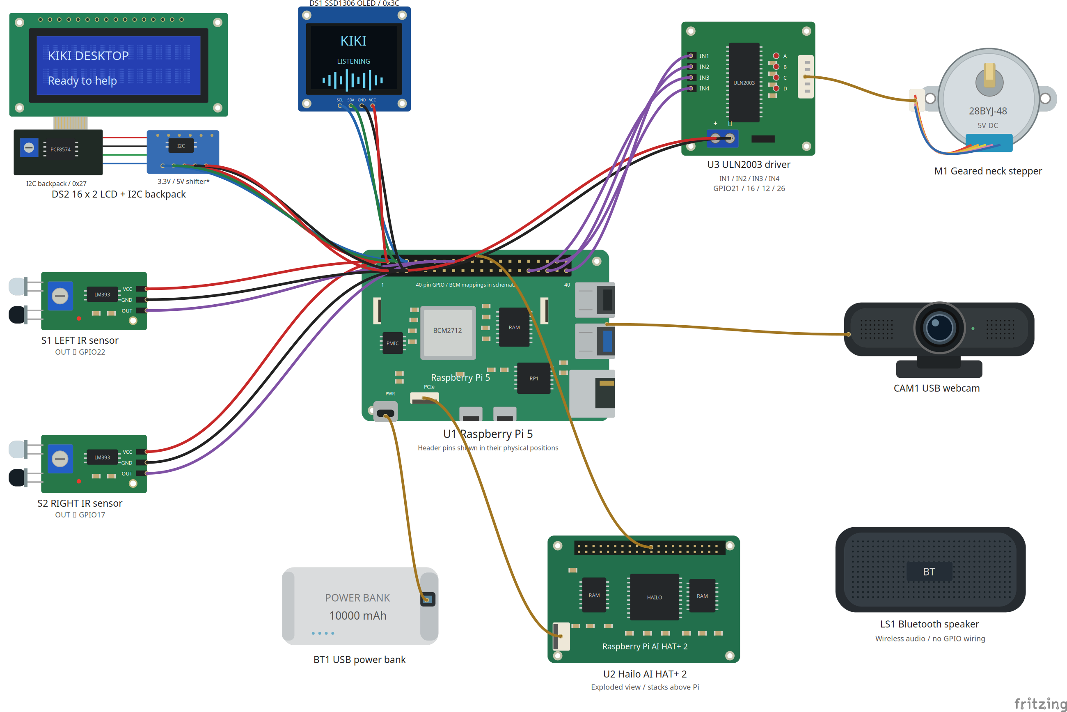
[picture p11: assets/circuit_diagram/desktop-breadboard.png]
Desktop wiring


| Part | Connection or setting |
|---|---|
| Compute and vision | Raspberry Pi 5, Hailo-8 accelerator, USB webcam |
| Camera stream | MJPEG on `localhost:5000` |
| Neck motor | 28BYJ-48 through ULN2003; GPIO 21, 16, 12, 26 |
| Front controls | Active-low LM393 IR sensors; left GPIO 22, right GPIO 17 |
| Character display | 16×2 LCD with PCF8574, I²C address `0x27` |
| Face display | 128×64 SSD1306 OLED, I²C address `0x3c` |
| Audio | Clavier One Bluetooth speaker |
| Power | 10,000 mAh USB bank; CPU capped at 2200 MHz |

A printed gear pair trades motor speed for torque to turn the head. The IR controls handle push-to-talk, return-to-idle and settings. Both displays share I²C bus 1, protected by one process-wide lock.

We lowered the CPU clock after power problems under combined load. A 1 Hz flight recorder now records system state to help distinguish brownouts from thermal shutdowns or software crashes.

### Wearable

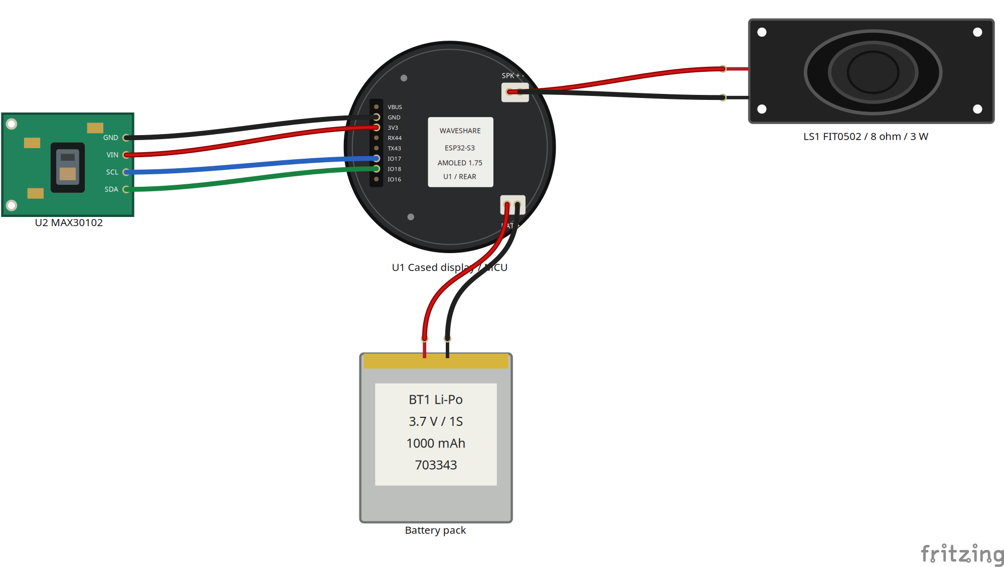
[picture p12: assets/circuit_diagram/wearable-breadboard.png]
Wearable wiring


| Part | Connection or setting |
|---|---|
| Board | Waveshare ESP32-S3-Touch-AMOLED-1.75; 466×466 touch display, 8 MB PSRAM |
| Heart-rate sensor | MAX30102; separate I²C bus, SDA GPIO 18, SCL GPIO 17, address `0x57`, 25 kHz |
| Motion | QMI8658 at 8 g / 1024 dps, sampled at 50 Hz |
| Audio input | Two microphones through ES7210 |
| Playback | ES8311 codec, NS4150B amplifier, 8 Ω 3 W speaker |
| Power | AXP2101 and a 1S 3.7 V, 1000 mAh cell |
| Firmware | C++, ESP-IDF 5.5 |

Internal RAM was tighter than CPU time. The linker reported 341,760 bytes of DIRAM, with roughly 166 KiB left after static allocation. Meanwhile, most of the 8 MB PSRAM was unused.

Moving the 66 KiB microphone queue and transmit/receive buffers to PSRAM raised free internal RAM from about 19 KiB to 84 KiB. The largest DMA-capable block grew from 7–12 KiB to 31 KiB, which made runtime allocation much less fragile.

The PLA enclosure uses a 60 × 72 mm base and holds the display module in its original 51 mm factory case. We changed to this arrangement after the AMOLED separated from the board during removal on 27 August. Four printed tabs now hold the case without pressing on the bare bezel.

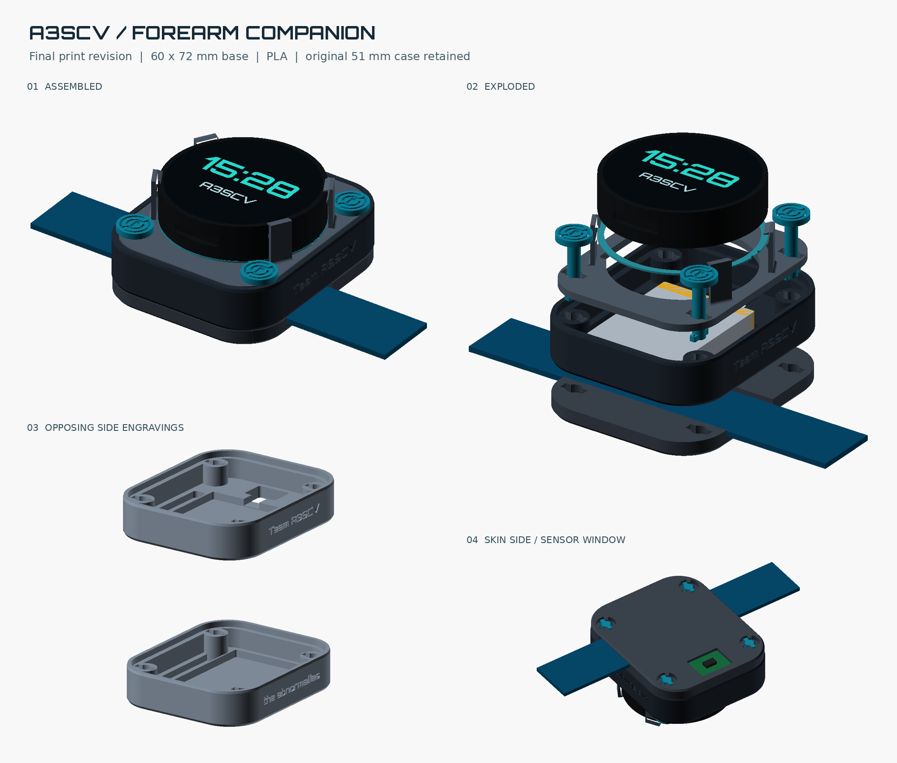
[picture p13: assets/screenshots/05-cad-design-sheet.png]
Wearable enclosure


A CAD review also caught tight wall clearances, an impractical detent and a font fallback before printing. Dimension assertions now catch some of those mistakes during regeneration. A custom PCB was postponed so we could finish the development-board version.

## Wearable audio and connection fixes

Raw 48 kHz, 16-bit mono audio needs 768 kbps in each direction. Our phone-hotspot/public-tunnel path only managed about 396 kbps. One run delivered just 74 of 3,449 microphone frames, with 16.5 seconds of playback gaps across a few replies.

Microphone audio now uses 16 kHz. Playback can use 48 kHz PCM on LAN, 16 kHz PCM remotely, or Opus at around 32 kbps. In the follow-up run, microphone frame loss was zero, playback underruns fell from 51 to 2, and total gaps dropped from 16,560 ms to 120 ms.

The playback start buffer stays at 100 ms. For more jitter tolerance, the gateway sends farther ahead instead of making the watch wait longer before speaking.

Two bugs took longer to find than the bandwidth issue:

- **WebSocket keepalive timeouts.** Sessions died even on a strong home Wi-Fi connection with no radio disconnects. `esp_websocket_client` shared a lock across sends, reads and keepalive pings, so a slow send could block the ping. One task now owns the socket, with other tasks feeding priority queues. The slowest LAN write measured afterwards was 2 ms.
- **Missing Opus audio.** Our binary parser rejected odd-length payloads, a check left over from 16-bit PCM. Opus packets can have odd lengths, so valid packets disappeared before reaching the decoder. The clue was a rate-limited `bad binary frame (33 bytes)` log. The parser needed to validate according to codec.

## Readings and fall alerts

Weather and air-quality data come from Open-Meteo. AQI is calculated from the latest hourly particulate values using CPCB breakpoints. It is an estimate on that scale, not an official station AQI based on the full averaging period and pollutant set.

Environmental snapshots are fresh for 30 minutes, stale until two hours, then unavailable. Unavailable snapshots omit environmental numbers so downstream code can't accidentally quote an old value. Failed pollutant fetches leave those fields empty rather than filling in a guess. A captured response is in [data/environment.snapshot.json](data/environment.snapshot.json).

Heat banding uses apparent temperature. Heart-rate storage accepts only GOOD or FAIR signal quality; a failed attempt can still be logged without saving its number as a trusted reading. SpO₂ is experimental and uncalibrated. It has a separate field and isn't treated as a health reading, despite appearing on an early prototype display.

### Fall detection

The detector runs in firmware over 50 Hz IMU samples. It requires:

1. Recent evidence that the watch is being worn.
2. At least 80 ms below 0.55 g.
3. An impact of at least 2.3 g within the next second.
4. Eight seconds of relative stillness.
5. A 30-second check-in before requesting an alert.

Candidates expire after 20 seconds, and a 60-second cooldown limits repeated alerts. Small movements after impact don't immediately cancel a candidate; a deliberate touch or spoken response does. Unworn drops are ignored.

These thresholds are heuristic. Controlled physical acceptance testing and clinical validation haven't been completed. Firmware detection works without a network, but sending a family alert requires the gateway and messaging service.

The [care-plan excerpt](data/care_plan.excerpt.json) includes a possible-fall request and its delivery record. `accepted: true` means the messaging tool accepted the send; `delivery_confirmed: false` means delivery wasn't confirmed. Neither says that someone read the message or that emergency services were dispatched.

## Camera activity checks

CLIP proposes activities on the desktop. An observation then passes through prompt geometry, margin/persistence, physical plausibility, vision-model adjudication and relevance checks before entering the care log.

The current prompt set has 11 positive activities and 17 negative distractors. Descriptions of visible movement worked better than inferred outcomes: “raising a cup or bottle to their mouth” was more useful than “drinking water”. The vision model gets an open question about the scene, and unclear answers or failed calls reject the candidate.

We removed the `unsteady` activity after it fired nine times in ten minutes on a healthy person. A single frame couldn't reliably distinguish steadying against a wall from standing beside one. Camera activity events aren't used for fall detection.

Accepted observations retain the vision model's wording in the care log. They're still observations, not proof that medicine was swallowed or an exercise was performed correctly.

## Care sessions

`care_plan.json` holds the profile, routines, family contacts, care log, session history and trusted readings. A routine supplies a `session_brief` describing its purpose; the care agent handles the conversation around it. That leaves room for someone to say their knee hurts or ask to stop.

Sessions end through a spoken stop request, an idle timeout or a turn limit (40 by default). We added these after a session appeared finished but stayed open internally for about twenty minutes, blocking other routines.

Hindi stop requests need explicit transliteration handling. Whisper once transcribed `बस` as `bus`, which the model interpreted as “just” and used to continue. Ordinary negative answers such as “no” or “नहीं” aren't global stop commands, since they can simply answer a question about symptoms.

Tool results determine whether an action can be reported as done. The same applies to session status: a cancelled interaction stays cancelled, and a session interrupted by a process restart is marked abandoned. It doesn't silently become completed.

## Checks and remaining work

Recorded test results from 8 September 2026:

| Suite | Result | Time |
|---|---|---|
| Desktop Python tests | 1,101 passed, 2 warnings | 26.96 s |
| Wearable gateway tests | 538 passed | 15.57 s |

These suites run without hardware or inference services. Firmware also has host-compiled tests for the protocol parser, motion classifier, panel state, transmit priority, IMU wire format and known Wi-Fi networks. Commands are in [src/README.md](../src/README.md).

The running system had ingested 209 telemetry batches and recorded 18 possible-fall alerts by that snapshot. Those counts describe development use; they don't measure detection accuracy.

The analytics pipeline currently uses generated data, and the caregiver dashboard has a separate SQLite database. Connecting both to `/api/care/v1` is unfinished. The TFLite experiment is separate from firmware fall detection. Sleep remains voice-logged, and SpO₂ still needs calibration and validation before it can be used as a health reading.

Build photos, circuit sources and CAD files are under [assets/](../assets/). The ₹1,110 sensor purchase was only part of the build cost. Our wearable BOM target is roughly ₹4,000–5,000; it isn't a verified production cost.

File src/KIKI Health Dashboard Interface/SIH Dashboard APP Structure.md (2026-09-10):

# SIH Dashboard APP Structure

This document outlines the product specifications, architecture, and feature breakdown for the KIKI Health Dashboard.

## Key Modules
1. **Onboarding Flow**: 3-step personalized setup (Personal Details, Activity/Location, Daily Goals).
2. **Dashboard**: Daily rings, metric cards, and heart rate trends toggle (graph/summary).
3. **Weather & Heatwave Advisory**: IMD heatwave protocols, AQI, and local alerts.
4. **Sleep Monitoring**: 7D/14D duration trends and sleep stages.
5. **Safety Center**: Fall detection alerts and emergency triggers.
6. **Heart Rate Alerts**: Clinical symptom assessments for high and low HR.
7. **Profile & Goals**: User settings, baseline customization, and account reset.

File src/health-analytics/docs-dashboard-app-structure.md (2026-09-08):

# SIH Dashboard APP Structure

First when user has first time entered the app ( only the first time , when you have no login information about the user) , he should go through these four cards 

First - the card of onboarding_personal_details_2

Second - onboarding_location_2

Third - onboarding_daily_goals_1

After details - there should be buffer time in setting up the user details and storing it back (You can use SQLite database for it , or any other database if you need to store user details)

After that - 

Premium_dashboard should appear as according to user and their data you have at that point for now , adjust everything accordingly. The API’s , user’s data collected from sensor etc. will be given later.

at the bottom we have nav bar for going to different pages , and also on the main page we have options for going to different pages . Those different pages are of Weather and heat index page - For this just build the UI , and frontend , it will function well , once it’s API will be given , which is not right now . And then the sleep pattern . Make sure the options for these pages in the nav bar and the their cards on the main dashboard , redirect the user to their official pages. 

There are two other pages as well , one is High heart rate health page , and low heart rate health page , For this - It will be shown - First : in the profile page log button ( which will be told later) and second it will show when the card made will show high heart rate , then their will be a button popping up at that time which will direct it to high heart rate , and similarly when the card will be showing low heart rate , and button will pop up at the same place for the low heart rate page.
This high heart and low heart rate will pop up with the help of a machine learning rule based model , which will be prepared later , since it is a backend , and your job is just for frontend , so dont go that way , just keep space for it to merge later and make sure the front end is not making conflict with it.

Last - The profile page , make it as it is and in sync with the database given by the user to app.
All the details of the profile to be shown here , the log buttons have the function here , the fall detection page to be displaced and user to be redirected to that page , once user clicks the fall detection option .
On Clicking the heart rate alerts log button user will be redirected to another log button page with same Ui and with now two different log button options, one for high heart rate alert and one for low heart rate alert , and then those pages of high heart rate will be displaced when user will click the high heart rate option and low heart rate when user will click the low heart rate option.

iN THE EDIT PROFILE AND EDIT GOALS detail , user would be redirected to the same input cards page which was shown at the beginning to edit the details and the edited details will be updated in the database with all changes synced on the particular pages that are using those data.

For now do these. Make sure there is no disturbance in the design , and app would be functioning well on the frontend side and the data side . Make it perfect.

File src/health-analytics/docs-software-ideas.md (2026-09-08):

# SIH Ideas for Software Part

## Ideas regarding databases (SQLite) -

- Basically Adding a feature every 15 minutes recording , like total 96 readings in a day (24*4) is a great idea.
- We will take inputs from the user about his ongoing life style , like how many hours does he sleep and between what to what time , how much does he exercise ( like 2-3 times per week , or something related) for better output and readings. - **We can basically ask these on mobile interface , while setting it up , and then update in our database and can make our model act accordingly.**

## Overall Project Structure -

```markdown
HeartRate_AI_Project/
│
├── esp32_firmware/ 
│   └── esp32_firmware.ino       # 1. ESP32 Code (Reads sensor & sends JSON) (C++)
│
├── database.py                  # 2. Database manager (Creates table, inserts & fetches data)
├── data_collector.py            # 3. Listens to ESP32 and stores readings in SQLite
├── model_inference.py           # 4. Loads Deep Learning model & runs predictions on SQLite data
└── main.py                      # 5. Master runner (Runs collector + Real-time AI prediction)
```

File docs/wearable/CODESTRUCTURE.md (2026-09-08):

# Kiki ESP32 — end-to-end code structure

> **Exercise 3D instructor (2026-09-07, built; NOT flashed):** The Cerebras care
> agent explicitly selects a seated 3D demonstration, anatomical side, pace and
> repeat/hold pattern. Six movements render locally on the watch with a PSRAM
> depth buffer. Preparation accompanies speech; motion starts after playback
> drains and ends with the timed hold. Stop, disconnect, fall checks and bounded
> timeouts close the screen. No animation is inferred from speech or wrist data.
> Gateway tests pass (489); host movement and existing panel/audio/motion checks
> pass. A stale fall-detector test disagrees with the unchanged deployed threshold
> rule; details are in `docs/EXERCISE_INSTRUCTOR.md`. No live deployment or OTA:
> the user will say when to flash. Package: `build/exercise-instructor-20260907/`.
> Final OTA build ID: `369ba888` (2,068,608 bytes).

> **Watch-style dashboard (2026-09-06):** Flashed/hash-verified `60761181` adds
> four rounded native LVGL cards (lime activity, pink HR, blue weather, amber
> estimated AQI), a 180x90 mascot, central clock and compact date. Native widgets
> are non-interactive so the existing touch/Stop/settings controls retain their
> events. Label updates are deduplicated; no additional network/model work.
> Firmware build and host panel-state tests pass. Physical visual acceptance
> remains pending. Previous `a045401d` image remains in deploy-dashboard-fall-20260906.
> Fall attempt at 19:36:06 armed a candidate but expired without eight seconds
> stillness; shaking speech is independent. This does not validate fall safety.

> **Idle dashboard / fall repair (2026-09-06, deployed):** The idle
> caption band now shows IST time/date, steps since boot, last valid HR and its
> age, plus cached RPi temperature/humidity and estimated CPCB AQI. Missing or
> stale values are labelled; speech, settings, dance and fall checks take priority.
> `panel_status.py` reads the existing health bridge cache every 30 seconds, with
> no prompt mutation or additional model-cache invalidation. The RPi health
> service exposes its existing EnvironmentProvider through the authenticated
> `/api/health/v1/environment` read-only endpoint (live on Pi).
> `kiki_fall_detector.hpp` consumes raw 50 Hz IMU samples, independent of the
> animation queue. It requires recent wear, >=80 ms below 0.55g, impact >=2.3g
> within 1 second, then 8 seconds stillness and a 30-second explicit check-in.
> A separate low-priority timer avoids the optical task's 40-second acquisition.
> Small movements no longer cancel an alert; touch/voice do. Candidates expire
> after 20 seconds; a 60-second cooldown suppresses duplicate episodes. These
> heuristic thresholds are NOT clinically validated and controlled physical
> acceptance remains pending. Unworn drops intentionally do not trigger alerts.
> 310 gateway tests, 12 RPi service tests and the host detector test pass. Firmware
> builds. Flashed and hash-verified build `a045401d`; its LAN hello was confirmed
> at 19:31:36 and microphone streaming resumed at 1.03x. Physical dashboard and
> fall acceptance are still pending. Previous firmware `46b2c738` and a verified
> 128 KiB boot/partition/NVS read are saved in laptop
> `deploy-backups/dashboard-fall-20260906/`. Full-flash reads failed without writing;
> the actual flash completed successfully and did not erase NVS.

> **Web UI feed repair (2026-09-06, deployed):**
> `observability_bridge.py` publishes normal ESP32 chat turns and model context to
> the existing recorder. Timestamp-based event IDs prevent restart cursor stalls.
> Recording failures are best-effort and cannot abort voice. No legacy source edit.
> Live `/api/events?since=9000` returned the new timestamp-ID startup event.
> Gateway currently runs as transient user unit `kiki-esp32-gateway.service`
> (PID 44950 at deployment) with the usual gateway log; use `systemctl --user`
> to manage this process. All 310 gateway tests passed on the laptop before restart.

> **Context-overflow repair (2026-09-06):** `gateway/kiki_gateway/context_budget.py`
> uses the local model's `/props`, `/apply-template` and `/tokenize` endpoints on
> the same normalized messages as generation, including tool instructions. It
> bounds the gateway reply cap to 512–1200 tokens plus 128 tokens of slack,
> and starts cloud compaction 768 tokens before that ceiling. The cloud task
> belongs to the shared core, is shielded from turn cancellation, and stages its
> result until a new turn boundary. It only replaces the exact summarized prefix
> and preserves newer messages. Prior conversation summaries are replaceable
> rows, not part of the permanent persona. Optional recalled memory is bounded
> when the prefix is built; mandatory persona/tool instructions are not truncated.
> Foreground and tool-result requests are checked before generation. If cloud
> compaction is late/offline, full snapshots are saved under gateway/context-archives
> before old short-term turns are pruned, preserving the current user/tool turn.
> An empty model result is retried once and then gets an explicit spoken failure,
> never a silently stored empty assistant message. Ordinary turns preserve their
> append-only cache prefix; only actual compaction/trimming rebuilds it. The
> original repair passed 302 tests on both Pi and laptop and was deployed.
> User subsequently confirmed voice works well. Legacy source is unchanged.

> **Wearable health (2026-09-03):** `firmware/main/kiki_wearable.*` owns the
> isolated GPIO18/17 MAX30102 bus, burst-FIFO I2C recovery, script-matched
> auto-gain/filtering, a continuous 10-second on-demand
> PPG, periodic stillness-gated PPG, steps, wear state, fall
> ladder, and three-batch NVS retry queue. `gateway/kiki_gateway/health_bridge.py`
> relays to the Pi port-8091 service on a background thread. `LegacyKikiCore`
> adds the material-change summary to its existing append-only
> `Now/Power/Body/Wearable` row; `gateway/legacy_kiki` remains unmodified.
> The sensor bus runs at 25 kHz with supplemental weak pull-ups; every recovered
> transaction timeout and FIFO overflow is counted into the capture verdict.
> FIFO data transactions have a separate 120 ms budget because a full
> 192-byte/32-sample drain itself takes about 70 ms at that bus rate; short
> register transactions retain their 30 ms bound.
> Pulse-interval timing is the rate source; ACF is only an independent
> confidence check and can never replace it. GOOD/FAIR normally requires
> peak/ACF agreement. The explicit alternating-notch path instead requires
> paired intervals, at least eight detected peaks, stable timing, and strong
> RED/IR agreement, so neither a hidden bus fault nor a weak half/double-rate
> estimate can be published as a wearable reading.
> Trusted optical telemetry carries `estimator_version: 2`; the Pi refuses an
> older queued window even if its firmware label claimed FAIR/GOOD.

> **Voice regression repair (2026-09-06):** The original health handler awaited
> the Pi HTTP ingest from the single WebSocket receive loop. Logs at 00:29–00:31
> show repeated 45-second connect timeouts, superseded connections, and microphone
> backlog. `session.py` now puts health batches into a bounded, deduplicated
> background delivery queue; the reader continues processing microphone, Stop,
> ping and `playback_drained` events while the Pi is unavailable. Disconnect
> cancels the delivery task; only Pi acceptance acknowledges a durable device
> batch. `health_bridge.py` uses a separate per-request connection with a
> 3-second connect / 45-second response timeout. `playback_drained` refreshes
> the 15-second reply window when the speaker actually finishes, so buffered
> playback cannot consume it. No firmware or legacy runtime change is needed.
> Deployed at 00:45; all 292 gateway tests pass on Pi and laptop. The physical
> Stop press at 00:46:40 cancelled the active response and the board reported
> `playback aborted; drained=232128 bytes, TX tail flushed`. A natural follow-up
> utterance after completed playback still needs explicit physical acceptance.

Everything needed to understand, build, deploy and debug the current ESP32 Kiki,
in one file. Written for an agent joining cold.

Companion docs: `docs/ARCHITECTURE.md` (why the split is where it is),
`docs/DEPLOY.md` (procedures), `docs/LATENCY.md` (measurements), `handoff.md`
(session history and constraints).

---

## 1. What this is

Kiki is a voice companion. This repo is the **ESP32 variant**: a Waveshare
ESP32-S3-Touch-AMOLED-1.75 is the audio/display body, and a laptop runs the
brain. The board never runs an LLM.

```
you speak
  → ES7210 mics → ESP32 I2S, 48 kHz, 10 ms frames
  → persistent WebSocket (LAN, or the internet via a tunnel)
  → gateway: RNNoise → 48→16 kHz FIR → Silero VAD
       240 ms silence: speculative Whisper   600 ms silence: commit
       the hotword is found in that TRANSCRIPT, not in the audio (§5.3)
  → legacy Kiki runtime: prompt + memory + tools + llama.cpp
  → sentence stream → OmniVoice TTS → PCM
  → same WebSocket → ESP32 jitter buffer → ES8311 speaker
```

The board owns: microphones, speaker, 466×466 AMOLED, capacitive touch, Wi-Fi,
playback buffering, the face, QMI8658 motion personality, and all on-panel UI. The laptop owns: everything
that thinks or remembers.

---

## 2. The three machines

| Machine | Hostname | Role | Path |
|---|---|---|---|
| Raspberry Pi | `kiki-1` (tailnet `100.64.0.11`) | **Repo of record + build host.** ESP-IDF lives here. Nothing at runtime. | `/home/kiki/kiki2/KikiESP32` |
| Laptop | `vaibhav` (tailnet `100.64.0.10`) | **Runs everything at runtime**: gateway, llama.cpp, Whisper, TTS, tunnel. | `/home/vaibhav/KikiESP32` |
| Board | — | The robot. | flashed image |

> **Note:** the laptop is **Linux** (LXQt, `systemd --user`), not Windows. If a
> Windows machine is meant to be in this system, it is not part of the current
> deployment — nothing in this repo targets it.

The laptop deployment is **not a git repo**. Changes are made on the Pi, then
`scp`'d over. `ssh vaibhav@vaibhav` (Tailscale) is the access path — note the
explicit user; plain `ssh vaibhav` tries to log in as `kiki` and is refused.

The Pi's own robot tree, `KikiFast`, is **read-only reference** for this project.

---

## 3. Repository layout

```
KikiESP32/
├── firmware/           ESP-IDF 5.5 project (built on the Pi)
│   ├── main/           all application code — see §4
│   ├── components/     vendored Waveshare BSP (locally patched, see §4.6)
│   ├── managed_components/  esp_websocket_client etc. (idf_component.yml)
│   ├── partitions.csv  flash layout
│   ├── sdkconfig.defaults   checked in — the real config source
│   └── sdkconfig       generated, gitignored, holds Wi-Fi + token secrets
├── gateway/
│   ├── kiki_gateway/   the gateway package — see §5
│   └── legacy_kiki/    the KikiFast runtime, copied to the laptop (gitignored)
├── scripts/            build / flash / run / tunnel / OTA — see §8, §9
├── docs/               ARCHITECTURE, DEPLOY, LATENCY
└── .tools/esp-idf      pinned ESP-IDF checkout (Pi only)
```

---

## 4. ESP32 firmware — `firmware/main/`

### 4.1 Boot sequence (`app_main.cpp`)

Order matters; each step depends on the previous.

1. `nvs_flash_init()` — erase and retry on version mismatch.
2. `ui_start()` — display, touch, LVGL, the face.
3. **Build banner**: `Kiki build <id>` where `<id>` is the first 4 bytes of the
   ELF SHA-256. *Not* the compile date — `esp_app_desc.c` is not reliably
   recompiled, so its date goes stale while the code moves on. This cost hours
   once; the ELF hash cannot lie.
4. Mic queue + `kiki_net_tx` task (priority 17, core 0).
5. `power_init()` — AXP2101 over I²C.
6. `audio_pipeline_start()` — codecs warm before the user finishes provisioning.
7. `motion_start()` — QMI8658 sampling + offline physical reactions; non-fatal.
8. `setup_ensure_wifi()` — **blocks** until a network is up (§6.1).
9. `time_sync(8000)` — **before** the gateway, because TLS needs a real date.
10. `ota_arm_rollback_watchdog()` — if this image arrived by OTA it now has
   180 s to reach the gateway or it reverts.
11. `gateway_client_start()`, `log_remote_start()`, telemetry task.

### 4.2 File map

| File | Responsibility |
|---|---|
| `app_main.cpp` | Boot order, mic uplink task, 5 s telemetry task |
| `wifi_station.cpp/.hpp` | STA connect, scan, NVS credentials, `forgotten` flag, power-save policy |
| `kiki_setup.cpp/.hpp` | On-panel Wi-Fi provisioning: scan list, touch keyboard, self-healing retry |
| `kiki_time.cpp/.hpp` | SNTP. Without it the clock is 1970 and every `wss://` cert is "not yet valid" |
| `gateway_client.cpp/.hpp` | WebSocket client, URI failover, framing, mic decimation, TTS expansion, and the **single owner of the socket** (§6.5) |
| `gateway_tx_priority.hpp` | Which control events overtake audio, and which are dropped first. ESP-IDF-free so `firmware/tests/test_tx_priority.cpp` can pin it |
| `kiki_panel_state.hpp` | What Kiki is doing vs. what her face is doing about it -- two things that were one variable until a mood tag disabled the Stop button (§13.15). ESP-IDF-free, tested by `firmware/tests/test_panel_state.cpp` |
| `protocol.hpp` | Binary frame header + `BinaryKind` enum (mirrors `gateway/protocol.py`) |
| `audio_pipeline.cpp/.hpp` | I²S in/out, ring buffer, adaptive jitter buffer, underrun accounting |
| `kiki_motion.cpp/.hpp` | QMI8658 task, runtime context, local reaction/event dispatch, telemetry |
| `kiki_motion_classifier.cpp/.hpp` | Platform-neutral posture/gesture/affect state machine |
| `kiki_ui.cpp/.hpp` | Face screen, status rows, hold-to-talk button, battery, media row |
| `kiki_face.cpp/.hpp` | The Clawd pixel-crab face, ported from KikiFast's `oled_display.py` |
| `kiki_dance.cpp/.hpp` | Dance mode: the full-panel stage, 26 parametric moves, and the media-sample beat clock (§5.5) |
| `kiki_dance_routine.cpp` | The routine parser alone -- no LVGL, no ESP-IDF, so it is host-testable |
| `kiki_theme.hpp` | One palette for every screen |
| `kiki_settings.cpp/.hpp` | Settings menu: volume, gain, brightness, persistent barge-in toggle, on-demand HR + experimental SpO2 screen, Change Wi-Fi, Shut down |
| `kiki_wizard.cpp/.hpp` | Boot wizard, ported from `startup_config.py` |
| `kiki_power.cpp/.hpp` | AXP2101: battery %, USB/charge state, charge current, soft power-off |
| `kiki_ota.cpp/.hpp` | HTTPS OTA download, 3 retries, rollback watchdog, `ota_result` |
| `kiki_log.cpp/.hpp` | Mirrors `ESP_LOG` to the gateway as `device_log` — debugging without a cable |

### 4.3 Flash layout (`partitions.csv`)

```
nvs       0x009000  0x006000
otadata   0x00F000  0x002000
phy_init  0x011000  0x001000
ota_0     0x020000  0x500000   ← app slot A
ota_1     0x520000  0x500000   ← app slot B
storage   0xA20000  0x5D0000
coredump  0xFF0000  0x010000
```

**The single most important operational fact in this project:** `otadata`
decides which app slot boots. A successful OTA repoints it at the *other* slot.
So after any OTA, flashing only `0x20000` writes the partition that is **not
running**, and the board comes up on the old image looking like the flash
silently failed. Always write `ota_data_initial.bin` to `0xf000` alongside the
app when flashing over USB.

### 4.4 NVS namespaces

| Namespace | Key | Meaning |
|---|---|---|
| `kiki_wifi` | `ssid`, `pass` | Panel-provisioned network (wins over Kconfig) |
| `kiki_wifi` | `forgotten` | Set by "Change Wi-Fi". **Suppresses the Kconfig fallback** — otherwise forgetting silently rejoins the built-in network and the button looks broken |
| `kiki_gw` | `fallback` | Public gateway URI learned from `hello_ack` |
| `kiki_ota` | `pending` | "This image arrived by OTA and must prove itself" |
| `kiki_ui` | `bright` | Screen brightness |
| `kiki_settings` | `barge_in` | User's persistent voice barge-in On/Off choice |

Erasing NVS (`esptool erase-region 0x9000 0x6000`) loses all of the above.
Nothing is fatal: the public URI is re-learned on the next `hello_ack`,
brightness resets, and the Kconfig Wi-Fi credentials take over.

### 4.5 Build-time config (`Kconfig.projbuild`, menu "Kiki ESP32")

`KIKI_WIFI_SSID` · `KIKI_WIFI_PASSWORD` · `KIKI_GATEWAY_URI` (LAN) ·
`KIKI_GATEWAY_URI_FALLBACK` (public) · `KIKI_GATEWAY_TOKEN` ·
`KIKI_AUDIO_VOLUME` · `KIKI_CHARGE_CURRENT_MA` · `KIKI_LOW_POWER` (dims the
screen only — it no longer touches the radio) · `KIKI_LOW_POWER_BRIGHTNESS`.

These live in `sdkconfig`, which is **gitignored** because it holds the Wi-Fi
password and the device token. `sdkconfig.defaults` is checked in and is where
non-secret settings belong.

Notable entries in `sdkconfig.defaults`:

- `CONFIG_ESP_WS_CLIENT_SEPARATE_TX_LOCK` **is not set** — with it enabled the
  component's receive task can close mbedTLS while the TX task is inside
  `mbedtls_ssl_write()`, which null-dereferences and reboots the board on a
  lossy remote link. This was the cause of the "restarts when I ask it
  something" reboots.
- `CONFIG_LWIP_DHCP_GET_NTP_SRV=y` + `CONFIG_LWIP_SNTP_MAX_SERVERS=4` — without
  the first, `esp_netif_sntp_init()` rejects any config asking for DHCP-supplied
  NTP, the clock stays at 1970, and TLS fails everywhere.
- `CONFIG_MBEDTLS_CERTIFICATE_BUNDLE=y` — for `wss://`.
- `CONFIG_ESP_COREDUMP_ENABLE_TO_FLASH=y` — crashes land in the coredump
  partition, readable with `esptool read-flash 0xff0000 0x10000`.

### 4.5a How much internal RAM there actually is

"~297 KiB" appeared in several comments and in this document and was wrong by
most of a factor of two, which matters because it is the number every
"is this small enough to put in internal RAM?" decision was weighed against.

From `idf.py size` on the current build:

| | bytes |
|---|---:|
| DIRAM the linker can see | 341,760 |
| ...used statically by the app (`.text` 94,403 + `.bss` 50,528 + `.data` 27,044) | 171,975 |
| **left for the runtime heap** | **169,785 (~166 KiB)** |
| IRAM | 16,384, **100 % full** |

The chip has 512 KiB of SRAM; the rest is cache and ROM reservations. On
hardware, `heap_caps_get_free_size(MALLOC_CAP_INTERNAL)` read 175,795 B right
after init (`docs/LATENCY.md`, 2026-08-12), so ~170-176 KiB is the real ceiling
and everything else -- task stacks, driver buffers, TLS, LVGL, the Wi-Fi stack
-- comes out of it.

That is the context for §6.5's queue placement. Before that change the board sat
at **19 KiB free with a 7-12 KiB largest DMA block** in steady state: about 11 %
of the pool, and close enough to the `ESP_ERR_NO_MEM` display floods of §4.6 to
be a latent fault of its own. Moving the 66 KiB microphone queue and the new
tx/rx buffers to PSRAM took it to **84 KiB free / 31 KiB largest DMA block**.

PSRAM is the opposite: 8 MB, of which about 7 MB is free even with the enlarged
768 KiB playback ring. Anything that does not need to be DMA-capable or touched
from an ISR belongs there.

### 4.6 The one patched vendor file

**Replacement-board baseline (2026-08-31):** the complete display/touch assembly and its
external I2C pull-ups are present again. The shared bus therefore runs at the BSP's normal
400 kHz, CST9217 touch and the audio codecs are required boot hardware, and the firmware no
longer carries the temporary internal-pull-up, optional-touch, or mute-boot paths. The
AXP2101's battery detection is enabled and percentage comes from its `0xA4` fuel gauge (with
the generic voltage curve only as startup fallback). The TS-pin measurement remains disabled
because Waveshare's own code does that for this board; that is board configuration, not the
old broken-connector workaround.

`firmware/components/waveshare__esp32_s3_touch_amoled_1_75/…_1_75.c` is
vendored and **locally modified**: upstream uses `buffer_height = 50` with
`use_psram = true`, which puts the LVGL draw buffer in PSRAM and forces
`spi_master` to allocate a 46,600-byte DMA-capable *internal* bounce buffer on
every flush. Internal RAM is the scarce resource here (~166 KiB, see below), so the display
failed with `ESP_ERR_NO_MEM` continuously. Now `buffer_height = 16`,
`use_psram = false`. The change is commented in place; do not let a component
update silently revert it.

### 4.7 QMI8658 motion personality

`kiki_motion.cpp` initializes the onboard QMI8658 through the BSP's existing shared I²C
bus using the pinned `waveshare/qmi8658` component. The sensor runs at 8 g / 1024 dps;
the classifier consumes samples at 50 Hz. Initialization is deliberately non-fatal so a
missing or faulty IMU cannot stop voice, display, networking, or OTA.

`kiki_motion_classifier.cpp` contains no ESP-IDF dependencies. It low-pass filters gravity,
extracts linear acceleration/jerk/angular speed, debounces posture, and emits semantic
situations: pickup, upright alert, face-down/upside-down/sideways, wiggle, escalating shake,
post-shake dizziness, rocking, spin, carried motion, bump, freefall/landing, set-down,
boredom/dozing, charging rest, music dance, low-battery tiredness, and wake-from-sleep.
Synthetic host traces live in `firmware/tests/test_motion_classifier.cpp`.

Two tasks keep the latency contract clean: the sampling task only reads/classifies/queues;
a lower-priority reaction task changes the face, requests a procedural local sound, logs,
and sends the debounced `motion_event`. A blocked WebSocket therefore cannot stall sampling.
Ordinary reactions overlay only idle/music/disconnected. Freefall and hard landing may briefly
overlay another face, but local audio still refuses to mix over speech or media. Runtime state
updates cancel the overlay and restore the authoritative gateway face.

The affect state is deterministic: boredom accumulates only face-up and idle; annoyance rises
with repeated shaking and decays during calm; gentle rocking reduces it. At 60 s/180 s/600 s
of untouched table idle Kiki fidgets, becomes visibly bored, then dozes. Touch, speech/runtime
activity, or meaningful motion resets that clock. The IMU cannot literally sense a hand, so
"held vertically" is inferred from upright posture, while the separate carried state also
requires sustained natural micro-motion.

---

## 5. Gateway — `gateway/kiki_gateway/`

Runs on the laptop. Entry point `kiki-esp32-gateway` → `server.run_server()`.

| Module | Responsibility |
|---|---|
| `server.py` | WebSocket server, per-connection `DeviceSession`, close-reason logging, event-loop lag watchdog |
| `session.py` | The whole conversation: hello/auth, mic → VAD → ASR → LLM → TTS, device events, OTA push. The big one |
| `config.py` | `GatewayConfig` dataclass; every field settable via `KIKI_GATEWAY_<UPPER>` |
| `protocol.py` | Binary frame header + `BinaryKind` (mirrors `firmware/main/protocol.hpp`) |
| `audio.py` | `RNNoise48k` denoise, `Decimator48To16` (7.2 kHz windowed-sinc FIR) |
| `silero.py` | Silero VAD (ONNX) |
| `hotword_text.py` | The wake word, matched in Whisper's text: fuzzy/phonetic scoring, per-mode hotwords, where in the sentence it landed (§5.3) |
| `wakeword.py` | openWakeWord "kiki" detector. **Off by default** — the fallback for a Whisper outage, `KIKI_GATEWAY_WAKEWORD_ENABLED=1` |
| `endpointer.py` | Streaming endpointer: speculative commit at 240 ms, conservative at 600 ms |
| `inference.py` | `LegacyKikiCore` (the real runtime), compact live time/power/body context, `DirectLlamaCore`, `WhisperClient`, `TTSClient` |
| `device_tools.py` | Tools the LLM can call that execute **on the board**: `adjust_volume`, `play_music`, `like_current_song`, `play_liked_songs`, `play_last_song`, `control_music`, `set_timer`, `switch_voice` |
| `display_bridge.py` | Routes the legacy runtime's 16×2 LCD + OLED output to the AMOLED |
| `expressions.py` | Face/expression cues |
| `motion_reactions.py` | Per-state speech cooldowns for journal-backed, never-repeat IMU questions |
| `dance.py` | Choreography: the move vocabulary, the cloud agent, the composer, the wire format (§5.5) |
| `beatgrid.py` | Tempo, downbeat and per-beat energy, measured from the audio with numpy alone |
| `config_store.py` | Serves the wizard's questions from the laptop's `config.json` |
| `audio_control.py` | TCP JSON control on `127.0.0.1:8770`: `status`, `gain`, `volume`, `sync`, `speak` |

Two tools sit beside the package, and everything in §6.5 was measured with them:

| Tool | What it is for |
|---|---|
| `tools/slowlink.py` | A bad network on demand: a userspace TCP proxy that shapes one flow (rate per direction, added RTT/jitter, retransmission stalls, scheduled outages). No root, no `tc`, no effect on ssh or the tunnel |
| `tools/fake_device.py` | The board without the board. Speaks the real binary protocol, replays the firmware's jitter buffer from arrival timestamps, and reports time-to-first-word split into **perceived**, **transport** and **gateway-reported** |

`audio_control`'s `speak` is the most useful debugging affordance in the system —
it makes Kiki say arbitrary text without needing a microphone:

```bash
python3 - <<'EOF'
import json, socket
with socket.create_connection(("127.0.0.1", 8770), timeout=90) as c:
    c.sendall((json.dumps({"action": "speak", "text": "hello"}) + "\n").encode())
    print(c.makefile("rb").readline())
EOF
```

### 5.1 Cache-safe live body and battery context

The firmware already reports `battery_percent` in `device_stats` every 5 s.
`DeviceSession._report_battery()` forwards the newest valid 0-100 reading to
`LegacyKikiCore`; `-1`, a missing field, or a malformed value clears it rather
than leaving a stale charge level in the prompt.

The existing periodic clock system anchor also carries the latest percentage
and active ten-point personality band: overcharged optimist (90-100), cocky mischief
(80-89), curious explorer (70-79), classic Kiki (60-69), cozy philosopher
(50-59), deadpan critic (40-49), dramatic complainer (30-39), clingy soft
friend (20-29), melancholic poet (10-19), or sleepy minimalist (0-9).

The same row carries a short semantic IMU summary such as
`Body: upright, moving; picked up 8s ago; calm.` Raw acceleration, gyro values,
numeric annoyance, and device-provided free text never enter the prompt. Posture,
activity, one fresh whitelisted event, and an annoyance band are the only body
fields. Ordinary events expire after 45 seconds; boredom/dozing/power-rest events
remain historical context for at most ten minutes. Telemetry older than 20 seconds
becomes `Body: unavailable.`

Every semantic `motion_event` also has a sparse gateway speech opportunity. Once the board's
local reaction is shown and the device is otherwise idle, `DeviceSession` asks the bundled
legacy runtime to reserve a random unused question for that exact movement state from
`thinking_journal.json`. The journal's permanent normalized asked ledger prevents an exact
question from ever being selected twice; an exhausted state stays silent until Unified Idle
Mind optionally adds fresh lines through `add_movement_questions(state, questions[])`.
The model's `no_action | reflect | light_research | deep_research` choice is unchanged and
adding questions is explicitly optional. A spoken motion question is appended to real model
history and opens the ordinary 15-second follow-up window, so the user's answer has context.
Global and per-state cooldowns prevent motion from becoming a speech stream.

The full dynamic row is only three short lines: `Now: …`,
`Power: 54% on battery (cozy philosopher).`, and `Body: …`. Interpretation policy lives
once in the stable startup prompt; the older verbose `current_time_context`
template is deliberately not repeated on live turns.
The combined row is appended at the configured five-minute interval or before
the next real turn after a meaningful semantic body change. Identical five-second
telemetry is deduplicated, and multiple events before one turn collapse into the
newest state.

No existing history row is rewritten or deleted. `LegacyKikiCore` supplies the suffix whether its own
foreground path or Unified Idle Mind requests that anchor: after the idle
manager is constructed, its per-instance `maybe_inject_time` callback is
replaced by the same gateway method, including the idle-time rewarm behavior.
This append-only shape is load-bearing: an ephemeral row removed after
generation would make the next request differ from llama.cpp's real cached
sequence and force old turns to be prefilled again. The durable system suffix
defines each band's behavior and makes it a noticeable secondary accent; the
user's needs, safety, facts, and Kiki's core identity still win.

An autonomous battery joke is controlled in code, not by asking the model to
remember a cooldown. The first conversational turn starts a monotonic clock.
After 90 minutes, the next turn receives one `BATTERY REMARK OPPORTUNITY` and
may make one short natural joke, including the exact percentage. The opportunity
is consumed when offered even if the model skips it during a serious moment.
Its system row remains in append-only history for cache correctness, but is
worded to apply only to the immediately following user message and to expire as
soon as its assistant reply exists; it therefore cannot authorize later remarks.
Direct battery questions are always answerable.
`KIKI_GATEWAY_BATTERY_REMARK_INTERVAL_SECONDS` overrides the 5400-second default
when intentionally testing the gate.

### 5.2 Configuration

`gateway.env` on the laptop, sourced by `scripts/run_gateway.sh`:

```
KIKI_GATEWAY_WEBUI_PORT=8092
KIKI_GATEWAY_TOKEN=<32-byte hex, must match CONFIG_KIKI_GATEWAY_TOKEN>
KIKI_GATEWAY_PUBLIC_URI_FILE=/home/vaibhav/KikiESP32/public_uri.txt
KIKI_GATEWAY_PENDING_OTA_FILE=/home/vaibhav/KikiESP32/pending_ota.txt
KIKI_GATEWAY_HOTWORDS="kiki,tiki,ki ki,piki"
```

`KIKI_GATEWAY_HOTWORDS` is the fallback name list (§5.3) — the one used by
every mode that does not name its own, so adding spellings here does **not**
stop `rohan` answering to "rohan". Whisper writes the same sound several ways
and the fuzzy score covers most of it, but a spelling it splits into two words
(`ki ki`) can only match as an entry of its own: a single-word hotword is
compared against single tokens. Multi-word entries are matched as a phrase, so
`ki ki` also brings `ti ki` in fuzzily. Quote any value containing a space —
`run_gateway.sh` sources this file.

`KIKI_GATEWAY_HOST` defaults to `0.0.0.0`. Setting it to `127.0.0.1` is the
supported way to **force the board onto the remote path for testing** without
sudo or travelling: the LAN address stops answering, so only the tunnel works.

### 5.3 The hotword lives in the transcript

Background listening is always on here: every utterance is endpointed and sent
to Whisper whether Kiki is awake or not, because idle speech becomes ambient
context. The name is therefore already in **text** before anything has to act
on it, and openWakeWord was answering the same question a second time, worse.
It is off by default now (`KIKI_GATEWAY_WAKEWORD_ENABLED=1` brings it back as a
Whisper-outage fallback); `hotword_text.py` + `session._finalize_turn` own the
wake decision.

Three things follow, and none of them were possible acoustically:

**Near misses wake her.** The score is the better of two measures: raw
`SequenceMatcher` on the letters, and equality of a *phonetic skeleton*
(consonant classes plus a vowel class per vowel run). "hey tiki" matches on
letters (0.75, exactly the default threshold — raising it drops the case this
was asked for), "kicky"/"keeki"/"kikki" match on sound. Only an **exact**
skeleton match scores, and vowel runs keep their colour, because the looser
versions of both answered to "okay", "cookie", "quick" and "geeky". The
rejected list is pinned in `tests/test_hotword_text.py`; treat it as the spec.

**Each mode answers to its own name.** `LegacyKikiCore.active_hotwords()`, read
fresh every utterance so a spoken mode switch takes effect immediately:
`assistant_modes.modes.<mode>.hotwords` → `assistant_modes.hotwords` → **the
mode's own `voice`**. That last step is the convention that makes it work on a
config file nobody edited: a mode owning a voice is a character with its own
name, so `rohan` answers to "rohan" and `jarvis` to "jarvis", while `default`,
`tutor`, `evil` and `senior` leave `voice` empty because they *are* Kiki and
fall through to `KIKI_GATEWAY_HOTWORDS` (default `kiki`). The idle panel row
shows whichever name is live.

**The name may come last.** "what do you think kiki" is not a question on its
own — the question was the previous utterance, seconds earlier and already
filed as ambient. `session._carry_back_text` prepends recent idle speech
(≤25 s, ≤3 utterances) when the geometry says the utterance is an *address*
rather than a question: at most `HOTWORD_CARRY_BACK_MAX_LEAD_WORDS` (6) before
the name and `..._MAX_TRAIL_WORDS` (2) after it. "kiki what's the weather"
fails the trailing test and is answered alone, which is the point — prepending
old chatter there would corrupt a perfectly good question. Carried text is used
once and the buffer is cleared, or it would be prepended to the next question
too. `[BLANK_AUDIO]`-style ASR narration never enters the buffer.

Her name and nothing else ("kiki", "hey kiki") with nothing to carry back opens
the listening window silently — the old wake word's exact behaviour.

**Latency is unchanged**, and that is what `hotword_speculative` is for. Idle
speech is transcribed at the 240 ms speculative endpoint, not only at the
600 ms commit; a hotword found there wakes the panel and prefills the box
immediately. It is not a second Whisper call — the commit path already reuses
that task. Because it is speculative it can be wrong, so the generation is
remembered (`_early_wake_generation`) and the window is closed again if the
final transcript does not confirm the name. A text hotword **never resets the
endpointer**: unlike a button or an acoustic wake it arrives *during* the
sentence it belongs to, and resetting would delete the utterance in flight.

Tests: `tests/test_hotword_text.py` (scoring, false positives, geometry),
`tests/test_hotword_session.py` (the wake decision, carry-back, early wake).

### 5.4 Face down is do-not-disturb

Turning Kiki onto her face is the one instruction that needs no screen, no
button and no sentence, so it is absolute. `session.note_posture()` sees the
posture change and `_enter_do_not_disturb()`:

* **stops what she is doing** — `cancel_turn` aborts generation and TTS and
  calls `device.stop()`, so speech and music both end;
* **closes the listening window** (`awake` is cleared *before* the cancel, so
  the state it settles on is `idle` and not an open window nobody asked for);
* **refuses to start anything of her own** for as long as she stays there.
  One check in `speak_background` covers every autonomous voice route —
  startup lines, worker and idle-mind speech, the journal's movement questions
  — and `ask_proactive_question` refuses separately so the scheduler logs why
  and retries later rather than burning its slot. `_handle_motion_event`
  checks it too, because `face_down` has a question bank of its own and the
  gesture that means *be quiet* must not be the one that speaks.
* Answering a **direct** question still works. Do-not-disturb stops Kiki
  interrupting you; it is not a mute switch on a question you chose to ask.

Two sources feed `note_posture`, and only a *change* acts: `motion_event`
carries the flip as soon as it happens, and `device_stats.imu_posture` (every
5 s) keeps the answer true afterwards — including for a session that connected
while she was already face down, where the event happened before the socket
existed. Only a posture the classifier is sure of ends the mode: `unknown`
is what it reports when it cannot tell, and letting one bad sample read as
"turned back over" would cancel do-not-disturb at random.

The panel says so on the ordinary status rows (`Do Not Disturb` / `Face down`),
sent as an `lcd` event rather than a new `state` name — the state machine that
would have to learn one lives in firmware, and a message explaining why Kiki is
quiet must not require an OTA to appear. `set_state` re-asserts it on every
return to `idle`/`followup`, or answering one direct question would leave
`Say 'kiki'` on a device that is still refusing to start anything. The board's
own `motion_face_down` reaction (the sulk face) is unchanged and needs no
firmware work.

Tests: `tests/test_do_not_disturb.py`.

### 5.4a Why she reconnected, and why it was never the Wi-Fi

Home wifi was fine. Stable wifi far from home, through the same tunnel, was
fine. A phone hotspot or a contended college AP dropped the session every few
seconds to a few minutes. That much was known. What was wrong was the
conclusion drawn from it -- that this was a link-quality problem -- because the
same log, read again on 2026-08-19, showed sessions of **15 to 275 seconds on
the home LAN, at RSSI -23 dBm, with zero Wi-Fi drops**:

```
device dropped the connection (rcvd=None sent=None uptime=15.4s)
device dropped the connection (... sent=1011 keepalive ping timeout ...)
device link health: rssi -23 dBm (ok), wifi drops 0 (last reason 0), ws drops 3
device firmware build 914f5969 ... link=lan
```

The radio was never the problem. A bad link only made an existing defect fire
constantly. See §6.5 for what it actually was and what owns the socket now.

The uplink gating described below is still here and still worth having, but it
is now the **default on any remote link** rather than something the board
switches on after it has already lost a session -- the old "wait for evidence"
trigger could only ever fire *after* the first drop, and it latched for the rest
of the boot so a link that recovered never got its ambient capture back.

The board uploads 16 kHz microphone audio **continuously** (~256 kbps), speech
or not, because the wake word is found in the transcript rather than in the
audio (§5.3). On a remote link that is most of what a phone hotspot has. Audio
therefore goes out around speech using the device VAD, with three guards against
the far worse bug of a deaf Kiki: only AEC-processed frames (the ones that carry
a VAD vote) are ever withheld, a 384 ms preroll is flushed on the way open so
the first syllable survives, and a short burst goes out every ten seconds
regardless. A quiet room's `audio_rate` reading well below 1.00x is therefore
expected on a remote link, not a fault.

Gating is a workaround for a frame costing 1 KiB on the wire, and it is the
first thing that should go once that frame is ~96 bytes of Opus.

**The board's black box.** A disconnect kills the device log that would explain
it, so RSSI, the Wi-Fi drop count and reason, and the websocket drop count ride
across in the next `hello` and are logged as `device link health`; RSSI also
joins the 5 s telemetry. From the gateway side a weak AP, a saturated uplink
and a bad tunnel look identical -- these separate them. Wi-Fi reason 2 is
AUTH_EXPIRE, 8 is the AP disassociating you. **Read these before blaming the
radio**: `wifi drops 0` with a strong RSSI means the fault is above the link.

### 5.4b One Kiki per process, not one per WebSocket

`server.py` builds a `DeviceSession` per connection. It used to build a whole
`LegacyKikiCore` with it -- config, knowledge base, saved summary,
`register_history()` -- and tear it down again on close. The board reconnects by
itself, so on a college AP that ran every 15 to 275 seconds, and each one cost:

* **the conversation**, back to a two-message history;
* **a KV-cache warm**, with `state="warming"` on the panel -- the "Warming up
  model" nobody could explain;
* **a cloud summarization call**, spent on a fragment that was one dropped
  packet in the middle of a sentence;
* **the worker scheduler and Unified Idle Mind**, stopped and restarted -- and
  since `start_background` waits 30 s to settle, a link that dropped inside that
  window meant they never started at all.

None of that is per-connection state. The socket is; the mind is not.
`inference.get_shared_core(config)` builds the runtime **once per process** and
every session attaches to it. A reconnect now goes straight to `idle` with the
conversation intact.

Three details are load-bearing:

1. **Attach is a stack, not a slot.** Sessions genuinely overlap -- the board
   reconnects before its previous socket has been reaped, so the departing
   handler's `finally` runs *after* the new one has attached. A naive detach
   unbinds the live session and leaves Kiki unable to speak, play music or run a
   device tool until the next reconnect, silently. `detach()` promotes whatever
   is still attached. `DisplayBridge.detach()` has the same hazard and the same
   guard, comparing with `==` because a bound method is a fresh object on every
   attribute access and `is` could never match.
2. **Everything device-shaped is late-bound.** The worker scheduler and the
   proactive-question loop outlive every session, so they read
   `_speak_callback` / `_proactive_callback` at call time rather than capturing
   a bound method of a socket that closed hours ago.
3. **The summary is written when the conversation is over, not when the socket
   is.** That is process shutdown (`server.py` installs SIGTERM/SIGINT handlers
   -- a bare `asyncio.Future()` never sees the signal the service manager sends)
   or `idle_summary_seconds` (30 min) with no device connected. It is also
   guarded against re-summarizing history a previous save already covered.

Tests: `gateway/tests/test_shared_core.py`.

### 5.5 Dance mode

"Kiki, dance" turns the whole panel into a stage. The gateway picks a song,
measures its beat grid and writes a routine; the board owns the animation and,
crucially, the clock.

```
"kiki, dance"
  ├ session.respond   -> dance.is_dance_request() fast path (0 ms, no box)
  └ or the `dance` tool the speaking model emits
       -> DeviceToolBridge._dance()
            ├ intro line spoken (covers the wait, never over the music)
            ├ choreography agent (cloud) -> song + routine
            ├ yt-dlp resolve + ffmpeg (the ordinary media path)
            └ beatgrid.analyse_url() -> BPM, downbeat, per-beat energy
       -> dance_start event, THEN the first media frame
```

**The clock is the whole feature.** Beat position comes from
`audio_pipeline_played_samples()` — the media samples the codec has actually
consumed, minus its 30 ms DMA tail — measured against the queued-sample count
at the instant the song's first frame arrived (`dance_note_media_frame`). Wall
time cannot be used: it knows nothing about the prebuffer gate, the adaptive
jitter buffer or a network stall, and any of the three walks the choreography
off the beat and leaves it there. Underrun silence is deliberately not counted,
because it is time the speaker waited rather than music it played.

**The model composes; it does not animate.** `firmware/main/kiki_dance.cpp`
owns 26 hand-built parametric moves with anticipation, squash-and-stretch and
per-move filter strength (a robot has to snap, a body roll has to flow — one
global smoothing value cannot do both). `gateway/kiki_gateway/dance.py` turns a
song into *which* move happens on *which* beat. `MOVES` and `EFFECTS` are a
wire format: the integers in the routine string are indices into the firmware's
`DanceMove`/`DanceEffect` enums, so a move may be appended but never reordered.
`tests/test_dance.py` parses `kiki_dance.hpp` and fails if the two ever drift.

**Three layers, in falling order of authority**: the cloud choreography agent
(same provider and JSON guards as `complex_query`, via `core.brain.fast_cloud`
— the local speaking slot is never touched), the measured beat grid, and the
composer, which fills every gap, extends the routine to the length of the song
and can write the whole thing alone. The composer *always* runs: a dance that
depends on a cloud call succeeding is a dance that sometimes does not happen.

**The routine is a compact string, not JSON.** ~250 entries of
`beat,move,beats,intensity,effect` is about 3.5 KB and parses with `strtol`;
the same thing as a cJSON tree is tens of kilobytes of parse on a board with
~166 KiB of internal heap. Energy is one hex digit per beat and drives the stage
lighting and the equaliser without any DSP on the device.

**Stopping.** Six routes, one exit (`session.end_dance`, idempotent):
a tap anywhere on the stage, turning her upside down (`DANCE_STOP_POSTURE`,
acted on by *both* the board's own classifier and `note_posture`), the song
ending, `cancel_turn` (Stop button, open palm, barge-in), going face down, and
talking to her — `duck()` ends a dance instead of pausing it, because resuming
a routine mid-conversation puts her back on a beat grid the listener has lost.
The board stops locally and instantly on a tap (`audio_pipeline_stop_playback`
before the round trip) and *then* tells the gateway. Two firmware watchdogs
make the dance room impossible to get stuck in: no music within 12 s of the
routine arriving, or 3 s of no samples once it has.

**Audio always wins.** Rendering shares core 0 with the Wi-Fi stack feeding the
song, so `dance_render_frame` backs off to 100 ms frames once the board's
buffer falls below its own prebuffer target and to 200 ms once it is half
empty. A single 60 ms threshold was too blunt: by then the buffer is already
empty half the time.

**Stopping never blocks the display.** The touch handler runs on the LVGL task
holding the display lock, so `dance_stop` only latches the intent — a worker
task does the silencing and the `dance_stop` send (whose 5 s timeout, on a link
congested by the song being stopped, froze the panel for seconds), and the next
render tick restores the screen. `dance_fps` and `dancing` appear
in `device_stats` while a dance runs, and only then.

Config: `KIKI_GATEWAY_DANCE_*` (`dance_enabled`, agent deadline, analysis
seconds, `dance_min_beat_confidence`, `dance_default_bpm`, `dance_intro_line`,
`dance_max_seconds`).

The `dance` tool is registered into the live legacy runtime by
`inference._register_dance_tool`, re-applied on every config reload alongside
the hardware overrides — `gateway/legacy_kiki/` is a gitignored copy of
KikiFast, so a tool defined there would be lost on the next sync.

Tests: `gateway/tests/test_dance.py`, `test_beatgrid.py`,
`test_dance_session.py`, and `firmware/tests/test_dance_routine.cpp`
(host-compiled against `kiki_dance_routine.cpp`, which is kept free of LVGL and
ESP-IDF for exactly that reason).

---

### 5.6 `health_sih` — the SIH health companion

An **additive** mode. Everything in it is inert until Kiki is switched into a
mode that declares the `care` capability; in `default` the whole feature costs
one Python import and one dictionary lookup per turn. That is the design
constraint it was built under, and `tests/test_care_mode.py` plus
`tests/test_care_gateway_wiring.py` are the tests that hold it.

```
gateway/kiki_gateway/care/
  mode.py       the health_sih definition + the capability gate (fails closed)
  runtime.py    CareRuntime: the switch, and the only object the gateway calls
  plan.py       the care plan store -- versioned, file-locked, ON THIS MACHINE
  agent.py      the live care conversation, IMU-grounded
  imu.py        raw wrist motion -> measured features -> prompt evidence
  cadence.py    the hold countdown, played on the BOARD's speaker
  heart_rate.py drives the board's MAX30102 over the WebSocket
  tools.py      get/update_care_plan, start_care_session, measure_heart_rate,
                get_wearable_status, alert_family
  scheduling.py routine events -> the worker scheduler the gateway already runs
  care_now.py   the compact `CARE NOW` row on the live context anchor
  environment.py  Open-Meteo weather + CPCB AQI, no key, no Pi
  alerts.py     WhatsApp + email, with accepted / delivered / failed kept apart
  companion.py  seeded briefing / reflection / hydration routines (off by default)
```

**No Raspberry Pi is required.** The care plan, the wearable telemetry store and
the environment provider all run here. `health_bridge.py` still posts to the Pi's
port-8091 service when it is up, but `session._handle_health_telemetry` now
stores every batch locally FIRST and acknowledges the board on that -- so with
the Pi off, the band's three-batch queue drains instead of retrying forever.

**Why the package is vendored rather than imported.** Most of `plan.py`,
`agent.py`, `care_now.py` and `environment.py` are KikiFast's health stack,
copied and rewired. `gateway/legacy_kiki` (and `gateway/kiki_runtime`) are
snapshots of KikiFast that are re-synced wholesale, and both predate that stack
entirely -- no `core/health/`, no `care_voice_agent`, no `mode_has_capability`.
Vendoring is also what makes the package **root-agnostic**: it depends only on
`get_full_config`, `get_active_mode`, `run_agent_loop`, `fast_cloud` and
`tools.execute_tool`, all of which both trees have.

#### The evidence is wrist motion, not a camera frame

The RPi judges a guided exercise from photographs taken during the hold. This
body has no camera and does have a 50 Hz IMU on the wrist that is doing the
movement, so the substitution is straight across:

| RPi | Here |
|---|---|
| `capture_best_frame_b64()` during the hold | `imu_window_start` -> firmware ring buffer |
| JPEG attached to the Cerebras request | measured features as text in the prompt |
| `visual_observation` / `person_in_frame` | `motion_observation` / `band_worn` |
| byte-identical JPEGs = frozen camera | byte-identical samples = stuck sensor |
| `continuous_vision` on a routine | `motion_tracking` |

`imu.analyse()` computes what the model is told: movements counted, cadence,
degrees swept (the integral of |gyro|), stillness, wrist angle at each end,
intensity, and an impact flag. **Nothing in the prompt is an impression** --
handing a model 500 raw samples asks it to do signal processing in prose, and it
will happily oblige with numbers it did not compute.

The 2026-09-02 grounding repair carries over unchanged, because the failure it
fixed is about the model and not about the sensor: observation before verdict,
`instruction_followed` checked in code, first mismatch corrected out loud with
the microphone still muted, second one stops and asks, and **no evidence is
stated rather than guessed around**. A still wrist when a movement was asked for
is `"no"`, not encouragement.

`kiki_exercise.cpp` on the board records the window and closes it *on the sample
that completes it*, so the window is exactly the interval asked for regardless of
task scheduling. The wire format (int16 milli-g / centi-dps, little-endian,
base64) lives in the ESP-IDF-free `kiki_imu_wire.hpp` and is pinned against the
same literal vector on both sides -- `firmware/tests/test_imu_wire.cpp` and
`tests/test_care_imu.py` -- because a scale or endianness disagreement would not
fail loudly, it would produce plausible motion evidence that is wrong.

#### The care plan on the watch

`firmware/main/kiki_care_ui.cpp`, reached from Settings -> "Care plan". The plan
lives on the laptop; the board renders it and can act on it: tap a routine for
its time, title and the brief Kiki was actually given, then **Start now**,
**Turn off** (off, not gone -- a paused routine is dimmed and unscheduled, not
deleted) or **Delete** (two taps, arming lapses after 4 s, same shape as Shut
down). A live session shows as a red **End session** banner above the list --
one tap, no confirmation, because someone reaching for it wants it to stop now.

The board is a VIEW. It holds no care state beyond the last push, every action
goes to the gateway as `care_action`, and the list is only redrawn when the
gateway sends the whole plan back as `care_plan`. So the screen cannot show a
deletion that did not happen -- the same rule the rest of health mode follows
about never claiming an action succeeded.

Two switches sit beside it in Settings, persisted in NVS and **enforced on the
board**: `Fall alerts` and `Movement checks`. Fall detection runs in firmware
and has to be switchable while the gateway is unreachable, which is exactly
when a false alert is hardest to stop. The detector keeps RUNNING when alerts
are off -- its ladder needs continuous history, so re-arming from cold would
mean the first real fall after switching back on is the one it misses -- only
the alert is suppressed. Both switches are mirrored to the gateway as
`care_options` for one reason: so the care agent says "movement checks are
switched off" instead of "the band did not send a window", which is the
sentence a broken sensor produces.

#### Timing a hold out loud

`cadence.py` renders the per-second countdown and the short cues once, caches
them, and plays them through the board's speaker over the ordinary TTS PCM path
(the RPi spawns `mpv` at a local ALSA sink; there is no speaker on this
machine). The hold blocks with the microphone shut, and the IMU window is armed
first and runs slightly longer, because the movement starts when the
instruction ends rather than when the last tick plays.

With no player registered the hold still **takes the full time and still
records** -- only the beeps are missing. That degradation is deliberate: a
silent hold is survivable, a hold that collapses to a zero-second pause is not.

#### What it does not do

* Never states a heart rate the band did not report. A failed capture is an
  attempt in the care log, never a number (`tests/test_care_session.py`).
* Never claims to see anyone. There is no camera; the prompt says so.
* Never promises a plan edit, a schedule or a message without a verified tool
  result, and `alert_family` reports `delivered` / `accepted` / `failed` per
  channel rather than treating a tool's prose as a receipt.
* Seeded companion routines are OFF by default (`seed_companion_routines`).
  Things that speak on a schedule are switched on deliberately.

#### Where it touches the rest of the gateway

Five places, each a no-op outside health mode: `_apply_hardware_overrides`
(registers the mode and its tool schemas, re-applied on every config reload like
`dance`), `_build_system_prompt` (appends the health layer -- the mode declares
no `system_prompt` of its own, deliberately, or it would lose the battery
personality, the embodied-context row and long-term memory), `_execute_calls`
(care tools intercepted so they reach THIS plan and not the older `senior` file),
`_inject_time_and_battery` (one change-gated `CARE NOW` line on the existing
append-only anchor), and `session.respond` (a live session owns the microphone
until it closes).

Config: nothing is written into the shared `config.json`. Tunables live in
`care/settings.py` with `KIKI_GATEWAY_CARE_*` env overrides; the plan file
defaults to `gateway/care-state/care_plan.json`, deliberately NOT `senior`'s.

Status: the gateway half is deployed and tested (391 pass on both machines, the
same 6 pre-existing failures as before the change). The firmware half **builds
but has not been flashed** -- until it is, no `imu_window` ever arrives and the
coach says it cannot feel any movement, which is the honest degradation.

## 6. Networking

### 6.1 Choosing a network (`kiki_setup.cpp`)

`setup_ensure_wifi()` → `join_known_networks()`:

1. The NVS-saved network, 20 s.
2. The Kconfig network, 20 s — **unless `forgotten` is set**.
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

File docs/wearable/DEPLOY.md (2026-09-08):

# Deployment

## Laptop

The deployed directory is `/home/vaibhav/KikiESP32`. The existing
`/home/vaibhav/kiki_servers/server_manager.py` and `/home/vaibhav/KikiFast` are
not edited.

```bash
cd /home/vaibhav/KikiESP32
./scripts/install_laptop.sh
./scripts/run_gateway.sh
```

Optional `gateway.env` values:

```bash
KIKI_GATEWAY_TOKEN=choose-a-device-token
KIKI_GATEWAY_PORT=8765
KIKI_GATEWAY_LEGACY_ROOT=/home/vaibhav/KikiESP32/gateway/legacy_kiki
# Optional overrides; these defaults make Kiki initiate a grounded question
# at a random point every 20-30 minutes while the panel is idle.
KIKI_GATEWAY_PROACTIVE_QUESTIONS_ENABLED=true
KIKI_GATEWAY_PROACTIVE_QUESTION_MIN_SECONDS=1200
KIKI_GATEWAY_PROACTIVE_QUESTION_MAX_SECONDS=1800
```

`KIKI_GATEWAY_LEGACY_ROOT` is optional. When it is unset, the gateway now uses
the bundled `gateway/legacy_kiki` runtime. Set it to an explicit empty string
only for a deliberately bare `DirectLlamaCore` deployment; that mode has no RPi
persona, Unified Idle Mind, workers, or proactive questions.
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

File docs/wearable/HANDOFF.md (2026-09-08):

# Kiki ESP32 migration handoff

Last updated: 2026-08-13 (Asia/Kolkata)  
Implementation repository: `/home/kiki/kiki2/KikiESP32`  
Laptop deployment: `/home/vaibhav/KikiESP32` on host `vaibhav`  
Original project (read-only reference): `/home/kiki/kiki2/KikiFast`  
Laptop inference manager (read-only reference): `/home/vaibhav/kiki_servers/server_manager.py`
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

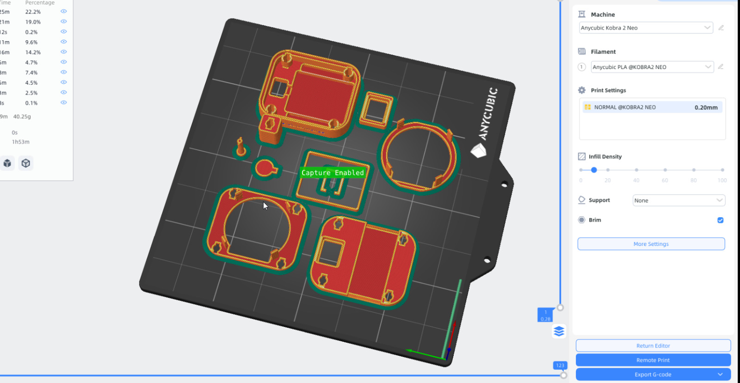
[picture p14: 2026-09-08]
assets/hardware/wearable-case-slicer.jpg

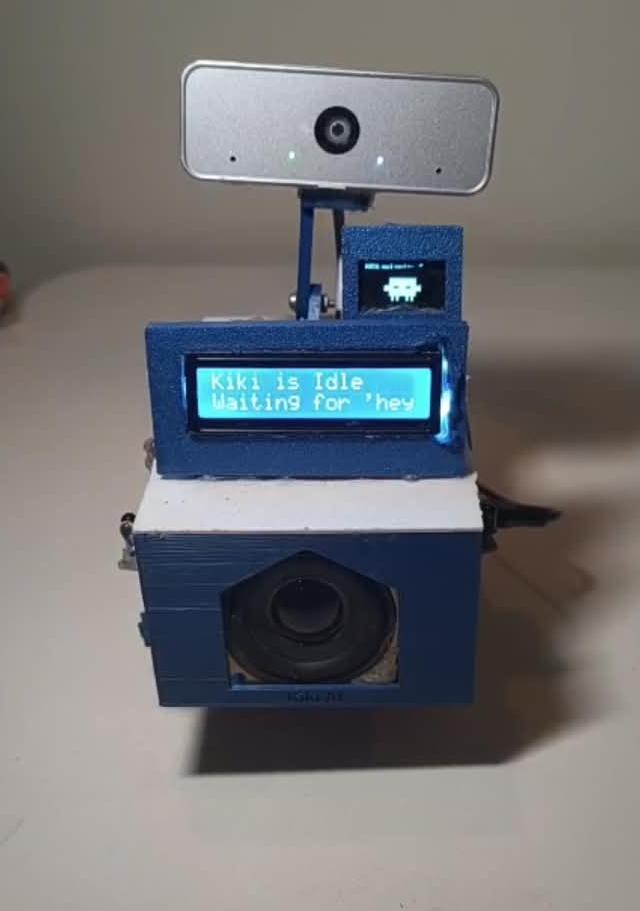
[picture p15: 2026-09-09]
assets/hardware/desktop-module.jpeg

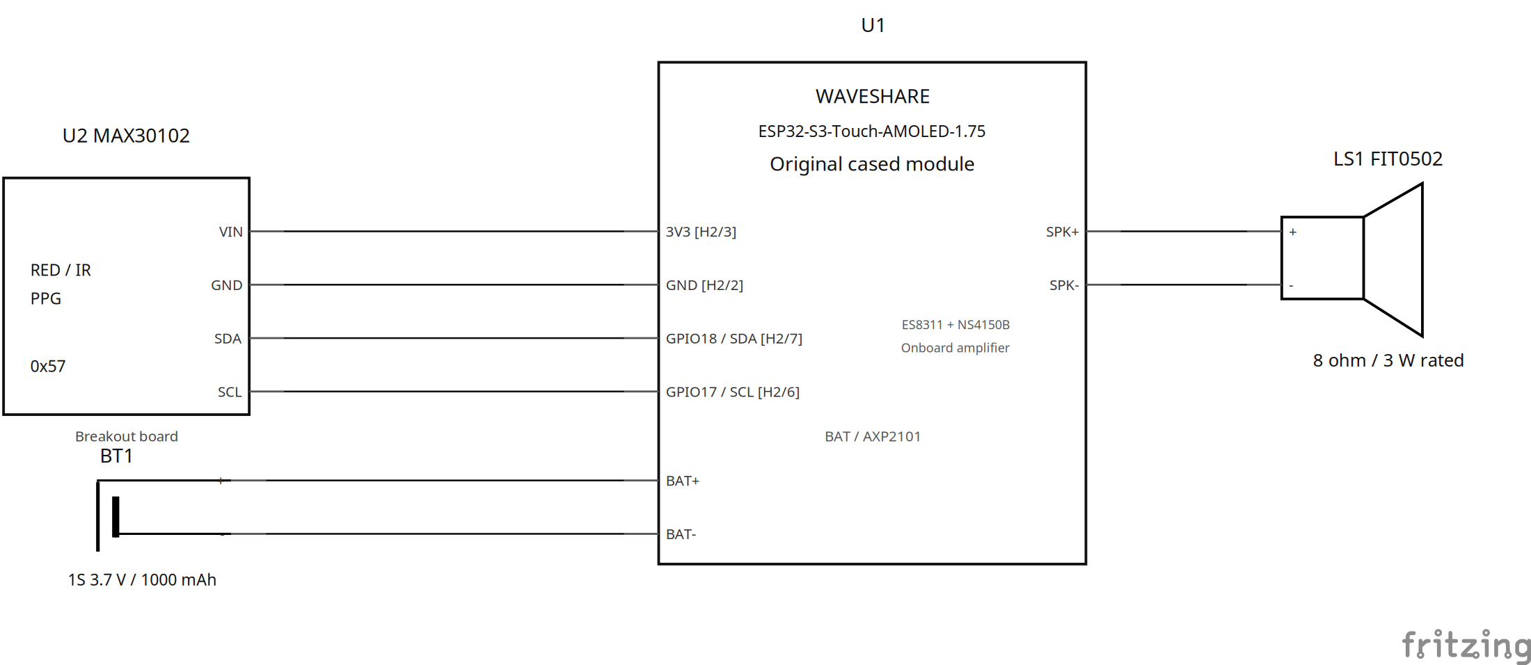
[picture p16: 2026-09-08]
assets/circuit_diagram/wearable-schematic.png

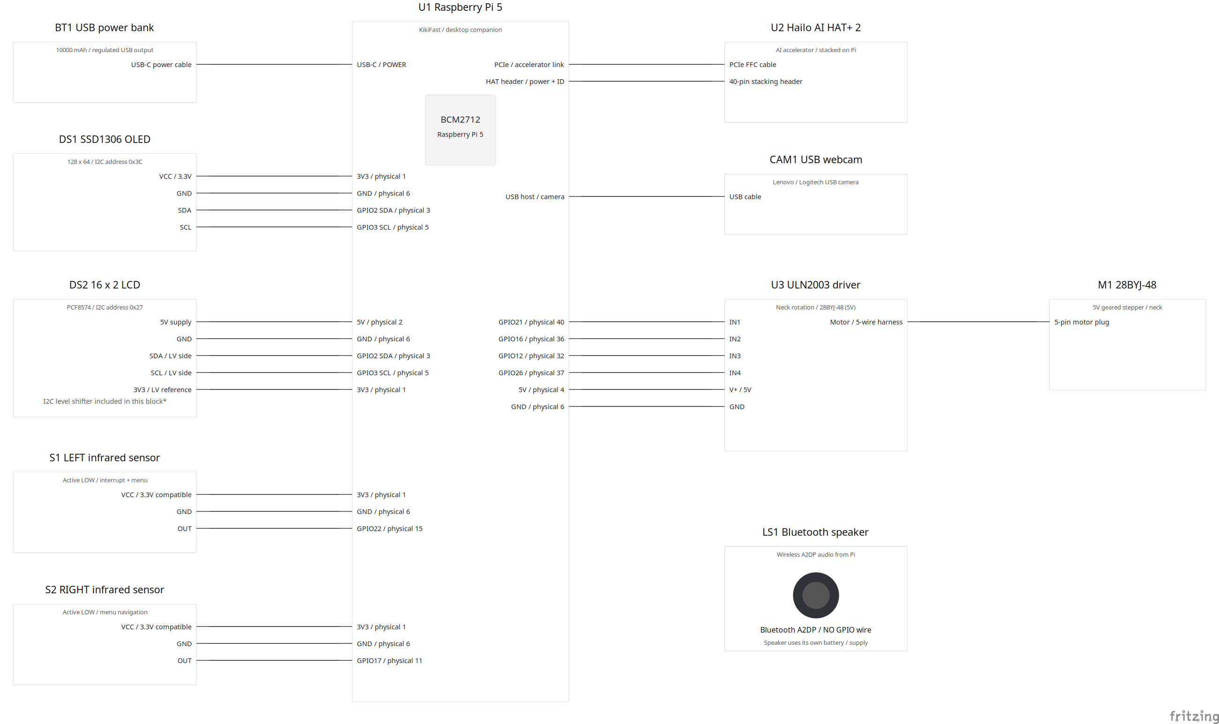
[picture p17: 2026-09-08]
assets/circuit_diagram/desktop-schematic.png

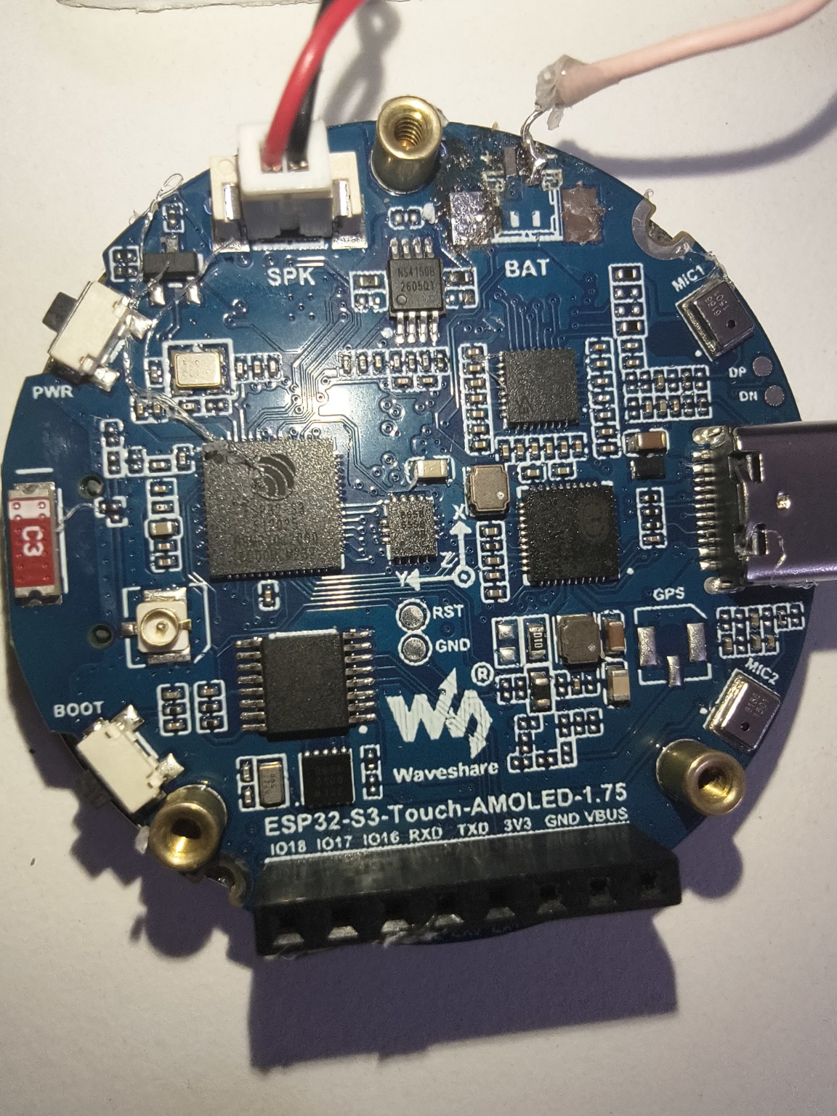
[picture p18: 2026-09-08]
assets/hardware/wearable-board-bare.jpg

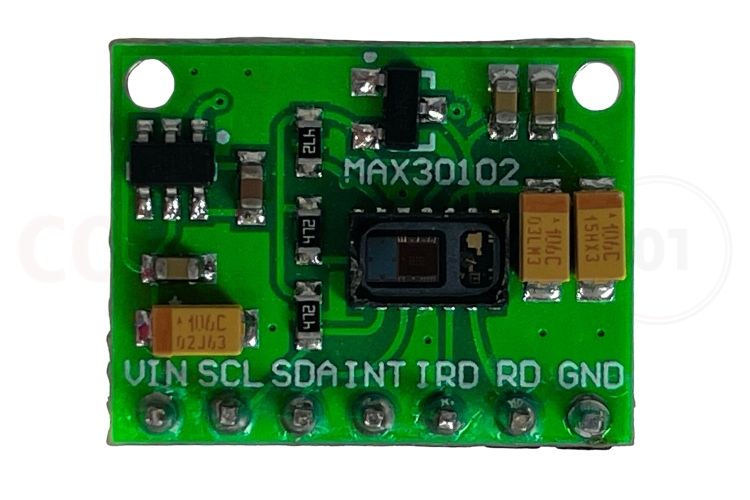
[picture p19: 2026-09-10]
assets/hardware/MAX30102-sensor.jpg

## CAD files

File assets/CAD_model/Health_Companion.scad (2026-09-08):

/*
  A3SCV forearm companion — final print revision, millimetres
  Original Waveshare case stays installed. All added hardware is printable.
  Read PRINT_INSTRUCTIONS.md. Physical fit and strength are not certified by CAD.
  Views: assembly, exploded, print_layout, tray, shoe, adapter, pin,
         keeper, turn_key, fit_case, fit_sensor, fit_lock, battery_gauge.
  Reference electronics and strap are NEVER included in individual part STLs.
*/

part = "assembly"; // [assembly, exploded, print_layout, tray, shoe, adapter, pin, keeper, turn_key, shim_032, shim_064, shim_096]
show_references = true;
$fn = 100;
eps = 0.02;

// Confirmed hardware / conservative battery envelope
case_d = 51;
case_h = 12.1;
battery_l = 43;
battery_w = 33;
battery_h = 8;
sensor_l = 18;                 // PCB dimension across the arm
sensor_w = 14;                 // PCB dimension along the arm
sensor_h = 5;                  // reserved component envelope, NOT optical height
strap_w = 22;
strap_thickness_allowance = 3.0; // measure actual fabric + stitching before printing

// Fit allowances are TOTAL additions, except named radial/per-side values.
battery_xy_clearance = 2.0;
battery_z_clearance = 1.2;
sensor_xy_clearance = 2.0;
case_radial_clearance = 0.50;
case_height_clearance = 0.70;
lid_per_side_clearance = 0.40;
pin_diametral_clearance = 1.00;
strap_width_clearance = 2.0;

// Envelope and layers: x across arm, y along arm, z away from skin.
body_w = 60;
body_l = 72;
corner_r = 14.5;
shoe_h = 2.0 + strap_thickness_allowance;
floor_h = 1.6;
battery_floor_z = shoe_h + floor_h;
lid_bottom_z = battery_floor_z + battery_h + battery_z_clearance + 1.5;
lid_h = 2.4;
case_z = lid_bottom_z + lid_h;
battery_y = -7.5;
strap_y = -7.5;
sensor_y = 25.2;

// Sensor face-down: seating ledge supports the PCB's component-side perimeter.
// Broad window exposes the sensor face and neighbouring components.
// Verify contact physically. Overall module height cannot determine lens height.
sensor_seat_z = 1.4;           // lower this to move PCB toward skin; re-export shoe+keeper
sensor_pcb_h = 1.6;            // provisional PCB thickness, separate from total 5mm envelope
sensor_keeper_gap = 0.35;
sensor_edge_overlap = 0.6;

pin_x = 22.8;
pin_y = 24;
pin_d = 4.1;
pin_head_d = 11.4;
pin_head_h = 2.0;
pin_lug_span = 7.3;
pin_lug_w = 2.0;
pin_lug_h = 1.8;
socket_roof_z = 2.2;
lock_axial_clearance = 0.12;
detent_r = 0.50;
head_spring_t = 0.8;
installed_shim_h = 0.64;       // preview only; supplied 0.32 / 0.64 / 0.96 mm shims

clip_angles = [30,150,210,330]; // clear the larger pin heads and the port axes
clip_w = 7.0;
clip_t = 1.4;
clip_rim_overlap = 1.0;        // catches OUTER case rim; check it misses display glass
case_contact_interference = 0.18; // small spring-pad preload to reduce case rotation

side_text_left = "the abnormalies";
side_text_right = "Team A3SCV";
letter_font = "Orbitron:style=Bold";
letter_size = 3.1;
engrave_depth = 0.65;

assert(sensor_seat_z > 0.8, "Keep at least 0.8mm beneath sensor seating ledge");
assert(shoe_h-sensor_seat_z-sensor_pcb_h-sensor_keeper_gap >= 0.6,
       "Keeper too thin: lower sensor_seat_z or increase shoe_h");
assert(battery_y+(battery_l+battery_xy_clearance)/2+2 <=
       sensor_y-(sensor_w+sensor_xy_clearance)/2, "Need battery/sensor separation");
assert(clip_rim_overlap <= 1, "Keep hooks on the outside case rim");

module rr2(w,l,r) {
    offset(r=r) square([w-2*r,l-2*r],center=true);
}
module rr(w,l,r,h) { linear_extrude(height=h) rr2(w,l,r); }
module at_pins() {
    for (x=[-pin_x,pin_x], y=[-pin_y,pin_y]) translate([x,y,0]) children();
}
module passage(z=-1,h=50) {
    translate([0,0,z]) linear_extrude(height=h)
        union() {
            circle(d=pin_d+pin_diametral_clearance);
            square([pin_lug_span+0.8,pin_lug_w+0.8],center=true);
        }
}
module pin_passages() { at_pins() passage(); }

module outer_tray() {
    // Chamfered lower edge, straight engraved sides, small upper chamfer.
    hull() {
        translate([0,0,shoe_h]) rr(body_w-1.2,body_l-1.2,corner_r-0.6,0.1);
        translate([0,0,shoe_h+1.0]) rr(body_w,body_l,corner_r,0.1);
    }
    translate([0,0,shoe_h+1.0])
        rr(body_w,body_l,corner_r,case_z-shoe_h-2.0);
    hull() {
        translate([0,0,case_z-1.1]) rr(body_w,body_l,corner_r,0.1);
        translate([0,0,case_z-0.1]) rr(body_w-0.5,body_l-0.5,corner_r-0.25,0.1);
    }
}

module side_engraving() {
    for (s=[-1,1])
        translate([s*(body_w/2-engrave_depth),0,(shoe_h+case_z)/2+0.4])
            rotate([90,0,s*90])
                linear_extrude(height=engrave_depth+0.3)
                    offset(delta=0.06)
                        text(s<0?side_text_left:side_text_right,
                             font=letter_font,size=letter_size,
                             halign="center",valign="center",spacing=1.02);
}

module tray() {
    difference() {
        union() {
            difference() {
                outer_tray();
                // Battery pocket, with rounded corners and clearance at pouch edges.
                translate([0,battery_y,battery_floor_z])
                    rr(battery_w+battery_xy_clearance,
                       battery_l+battery_xy_clearance,0.7,case_z);
                // Upper shared wiring space; 3mm-high battery locating walls remain.
                translate([0,0,battery_floor_z+3]) rr(body_w-8,body_l-8,9.5,case_z);
                // Adapter seats in this rebate; pin bosses remain below its underside.
                translate([0,0,lid_bottom_z]) rr(body_w-3.6,body_l-3.6,corner_r-1.8,5);
                // Low wiring gutters around the long sides of the battery.
                for (s=[-1,1]) translate([s*21,battery_y,battery_floor_z+0.4])
                    rr(5.4,39,1.4,case_z);
                // Sensor back / solder access, leaving perimeter to capture keeper.
                translate([0,sensor_y,shoe_h-eps]) rr(14,10,1,case_z);
                // Protected route from sensor backside into shared wiring space.
                translate([-3.5,14.5,battery_floor_z+0.4]) cube([7,12,case_z]);
            }
            // Full-height structural bosses bypass battery and sensor.
            at_pins() translate([0,0,shoe_h]) cylinder(d=9.6,h=lid_bottom_z-shoe_h);
        }
        pin_passages();
        side_engraving();
    }
}

module lock_socket() {
    passage();
    // Underside circular counterbore: lug is recessed away from skin.
    translate([0,0,-eps]) difference() {
        cylinder(d=9.3,h=socket_roof_z+eps);
        // Hard stops just beyond the 90 degree detent prevent a second quarter-turn.
        for(a=[112,292]) rotate([0,0,a]) linear_extrude(height=socket_roof_z+2*eps)
            polygon([[2.6,0],[5,0],[5*cos(25),5*sin(25)],[2.6*cos(25),2.6*sin(25)]]);
    }
    // Two shallow detent seats at the locked (90 degree) position.
    for (s=[-1,1]) translate([0,s*2.9,socket_roof_z]) sphere(r=0.72);
}

module shoe() {
    difference() {
        union() {
            // Flat print face, bevelled perimeter. No hidden underside supports.
            hull() {
                rr(body_w-2,body_l-2,corner_r-1,0.1);
                translate([0,0,0.9]) rr(body_w-0.6,body_l-0.6,corner_r-0.3,0.1);
            }
            translate([0,0,0.9]) rr(body_w-0.6,body_l-0.6,corner_r-0.3,shoe_h-0.9);
        }
        // Open-top channel becomes an enclosed strap tunnel when tray is installed.
        translate([-body_w,strap_y-(strap_w+strap_width_clearance)/2,2])
            cube([body_w*2,strap_w+strap_width_clearance,shoe_h]);
        // Chamfered channel entrances protect the fabric edge.
        for (s=[-1,1]) translate([s*(body_w/2-1),strap_y,2.0])
            rotate([0,45,0]) cube([2,strap_w+strap_width_clearance,2],center=true);
        // Sensor cavity and wide front aperture: no plastic across the optical face.
        translate([0,sensor_y,sensor_seat_z])
            rr(sensor_l+sensor_xy_clearance,sensor_w+sensor_xy_clearance,0.8,shoe_h+1);
        translate([0,sensor_y,-eps])
            rr(sensor_l-2*sensor_edge_overlap,sensor_w-2*sensor_edge_overlap,0.8,sensor_seat_z+2*eps);
        at_pins() lock_socket();
    }
}

module keeper() {
    // Loose frame clamped by the main tray; no screws, glue or PCB drilling.
    h = shoe_h-sensor_seat_z-sensor_pcb_h-sensor_keeper_gap;
    difference() {
        rr(sensor_l+sensor_xy_clearance-0.8,sensor_w+sensor_xy_clearance-0.8,0.7,h);
        translate([0,0,-eps]) rr(14.5,10.5,0.6,h+2*eps);
        // One wire exit preserves a connected C-frame; rotate keeper 180 if needed.
        translate([-8.5,0,h/2]) cube([5,6,h+1],center=true);
    }
}
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

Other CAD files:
assets/CAD_model/stl/kiki_desktop.stl

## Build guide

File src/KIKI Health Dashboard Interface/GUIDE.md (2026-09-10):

# KIKI Health Dashboard — Complete Project & Integration Guide

Welcome to the **Kiki Health Dashboard** project (Smart India Hackathon). This comprehensive guide is designed for all team members — frontend developers, hardware/IoT engineers, and AI/backend specialists — explaining how to clone, run, view, and contribute to this GitHub repository.

---

## 📌 1. Project Overview

**Kiki** is an intelligent, mobile-first health monitoring, environmental telemetry, and safety companion app tailored for Indian users. It bridges real-time physiological hardware telemetry with hyper-local environmental forecasts (IMD heatwave alerts, UV indices, air quality) and emergency safety mechanisms (fall detection and heart rate anomaly symptom assessments).

### Key Architectural Pillars
- **Mobile-First UX**: Premium dark-mode glassmorphic interface (OLED blacks, neon cyan, electric blue, and Indian flag accents).
- **Persistent Local Database**: Zero cloud dependencies during local testing via embedded SQLite (`better-sqlite3`).
- **Reactive Server Synchronization**: Next.js Server Components automatically re-render when new hardware or API telemetry is inserted into the database.

---

## 🛠 2. Tech Stack

- **Framework**: Next.js 14+ (App Router)
- **Language**: TypeScript (`strict` mode)
- **Styling**: Tailwind CSS with custom glassmorphism tokens
- **Typography & Icons**: Google Fonts (*Rozha One*, *Yatra One*, *Inter*, *Hanken Grotesk*) & Material Symbols Outlined
- **Database**: Embedded SQLite (`data/vitality.db`) via `better-sqlite3`

---

## 🗂 3. Project Directory Map

```text
KIKI Health Dashboard Interface/
├── KIKI-app/                         # Next.js Application Core
│   ├── app/
│   │   ├── api/                      # Backend Route Handlers
│   │   │   ├── onboarding/route.ts   # User registration & goal initialization
│   │   │   └── user/route.ts         # GET profile, PUT updates, DELETE account wipe
│   │   ├── dashboard/                # Main Home Screen
│   │   │   ├── HeartRateTrends.tsx   # Interactive Graph & Summary list toggle
│   │   │   └── page.tsx              # Rings, Calories, Steps, Metric Cards
│   │   ├── onboarding/               # 3-Step First-Time Onboarding
│   │   │   ├── personal-details/     # Step 1: Mascot & Tricolor "नमस्ते" Calligraphy
│   │   │   ├── location/             # Step 2: India-locked & City selection dropdown
│   │   │   └── daily-goals/          # Step 3: Steps & Calorie targets + Buffer animation
│   │   ├── weather/                  # Weather, AQI & IMD Heatwave Section
│   │   │   ├── Weatherindexpage.tsx  # Core weather component with 5 heatwave protocols
│   │   │   └── page.tsx              # Weather entry point re-exporter
│   │   ├── sleep/                    # Sleep Quality, Hardware Sync & Sleep Trends
│   │   ├── profile/                  # Profile & Preferences (Neon Blue / Cyan theme)
│   │   │   ├── edit/                 # Edit profile data (syncs to DB)
│   │   │   ├── edit-goals/           # Edit health targets (syncs to DB & Dashboard)
│   │   │   └── DeleteAccountButton.tsx# Account reset modal (wipes DB & starts fresh)
│   │   ├── fall-detection/           # Fall alert log & emergency contacts
│   │   ├── heart-rate-alerts/        # Clinical HR assessment logs
│   │   │   ├── high/                 # High HR (>100 BPM) symptoms & ECG equalizer
│   │   │   └── low/                  # Low HR (<60 BPM) symptoms & baseline comparison
│   │   ├── layout.tsx                # Global HTML shell & font imports
│   │   └── globals.css               # Global tokens, noise & dark mode CSS
│   ├── components/
│   │   ├── NamasteCalligraphy.tsx    # SVG Indian flag tricolor Devanagari calligraphy
│   │   └── SleepTrendsCard.tsx       # 7D / 14D sleep duration bar chart
│   ├── data/
│   │   └── vitality.db               # Embedded SQLite database
│   ├── lib/
│   │   └── db.ts                     # Database connection & table schema
│   └── public/
│       └── namaste_mascot.png        # Fit India Namaste character asset
├── Design/                           # Exported UI designs and wireframes
└── SIH Dashboard APP Structure.md    # Product and feature specifications
```

---

## 🌐 4. How to Clone, View, and Work with This GitHub Repo

Follow these steps to pull the code, launch it locally, and explore each feature:

### Step 1: Clone and Checkout the Branch
```bash
# Clone the repository
git clone <your-repository-url>
cd <repository-folder-name>

# Fetch and switch to the project branch
git fetch origin
git checkout <target-branch-name>
```

### Step 2: Navigate to the Web App
```bash
cd "KIKI Health Dashboard Interface/KIKI-app"
# Or run from the repository root: npm run dev
```

### Step 3: Install Dependencies
```bash
npm install
```
> *Note: SQLite dependencies (`better-sqlite3`) will compile automatically. No external database setup or Docker container is required.*

### Step 4: Run the Development Server
```bash
npm run dev
```
Open your browser and navigate to:
👉 **`http://localhost:3000`**

### Step 5: How to View the App (Crucial Step)
Because **Vitality** is designed specifically for mobile screens:
1. Open Chrome, Edge, or Safari DevTools (`F12` or Right Click ➡️ **Inspect**).
2. Press `Cmd + Shift + M` (macOS) or `Ctrl + Shift + M` (Windows/Linux) to toggle the **Device Toolbar**.
3. Select a modern mobile preset such as **iPhone 14/15 Pro**, **Pixel 7**, or set the viewport to **`390 x 844 px`**.

---

## 📱 5. Interactive Walkthrough of User Flows

When testing or demonstrating the app, follow this progression:

### A. Genuinely New User Onboarding
1. **Fresh Start**: If no account exists in SQLite, visiting `http://localhost:3000` immediately routes to `/onboarding/personal-details`.
2. **Step 1 — Personal Details**:
   - Features the Fit India Mascot and the shiny tricolor **"नमस्ते"** Devanagari calligraphy.
   - Enter Full Name, choose Gender, and pick Age via the stepper.
3. **Step 2 — Activity & Location Baseline**:
   - Country is locked to **India (IN) 🇮🇳**.
   - Select your city from top Indian metros (*New Delhi, Mumbai, Kolkata, Chennai, Pune, Ahemdabad*), or pick **"Any other - please tell"** to write your custom city.
4. **Step 3 — Health Goals & Setup Buffer**:
   - Select daily baseline steps (5,000 to 12,000) and active calorie burn (300 to 900 kcal).
   - Click **Save goals & continue**: Watch the animated setup buffer (*"Saving health profile..."* ➡️ *"Calibrating activity baselines..."* ➡️ *"Finalizing dashboard..."*) transition smoothly to the dashboard.

### B. Daily Dashboard Experience (`/dashboard`)
- **Interactive Metric Rings**: Real-time rings displaying calories burned and step counts calibrated against your personal goals.
- **Heart Rate Trends**: Click the **Summary** tab to see exact timestamps with heart rate values in list format, or switch back to **Graph** view. Filter across `TODAY`, `7D`, `14D`, and `30D`.
- **Navigation Bar**: Bottom navigation with active red indicator on Home, routing to **Weather**, **Sleep**, and **Profile**.

### C. Weather & IMD Heatwave Protocol (`/weather`)
- Severe Weather Advisory banner from IMD.
- 24-hour heat index & temperature curves.
- Air Quality (AQI) with PM2.5 monitoring.
- Interactive list of the **5 Heatwave Protocols** (Hydrate Regularly, Light Clothing, Shade & Cooling, Symptom Watch, Vulnerables & Pets).

### D. Sleep Quality & Trends (`/sleep`)
- Sleep stages breakdown (Deep, Light, REM, Awake).
- Interactive **Sleep Trends Card** toggling 7-day and 14-day duration bars and score curves.
- The **4 Sleep Protocols** (Consistent Schedule, Sleep Environment, Wind-Down, Sunlight Exposure).

### E. Safety Center & Clinical Assessments
- **Fall Detection (`/fall-detection`)**: Simulated fall event logs, severity flags, and emergency action triggers.
- **High Heart Rate Assessment (`/heart-rate-alerts/high`)**: ECG equalizer animation, above-range banner (`118 BPM`), and symptom multi-select grid.
- **Low Heart Rate Assessment (`/heart-rate-alerts/low`)**: Baseline comparison bar (`48 BPM`) and clinical advisory.

### F. Profile, Edits & Account Reset (`/profile`)
- **Neon Blue & Electric Cyan** aesthetic.
- **Edit Profile (`/profile/edit`)** & **Edit Goals (`/profile/edit-goals`)**: Update your details and see them immediately sync with the database and dashboard rings.
- **Delete My Account**: Click the red button to open the confirmation modal. Deleting wipes all database records and local storage, immediately returning you to the 3 onboarding cards to start fresh.

---

## ⚡️ 6. Hardware & IoT Sensor Integration Guide

The frontend is built to accept incoming hardware streams without requiring redesigns. Here is how your hardware teammates can plug their sensors into the app:

### 6.1 Real-Time Heart Rate Stream (`HeartRateTrends.tsx`)
- **Hardware Source**: Photoplethysmography (PPG) sensors (e.g., MAX30102, MAX30100), Bluetooth LE heart rate straps, or wearable microcontrollers (ESP32 / Arduino / Raspberry Pi).
- **Connecting the Sensor**:
  Create an API endpoint `app/api/telemetry/heart-rate/route.ts`:
  ```typescript
  import db from '@/lib/db';
  import { revalidatePath } from 'next/cache';
  import { NextResponse } from 'next/server';

  export async function POST(req: Request) {
    const { bpm } = await req.json();
    const user = db.prepare('SELECT id FROM users LIMIT 1').get() as any;
    
    db.prepare(`
      INSERT INTO health_data (user_id, metric_type, value, recorded_at)
      VALUES (?, 'heart_rate', ?, datetime('now', 'localtime'))
    `).run(user.id, bpm);

    revalidatePath('/dashboard');
    return NextResponse.json({ success: true });
  }
  ```

### 6.2 Sleep Patterns & Stages (`SleepTrendsCard.tsx` & `/sleep`)
- **Hardware Source**: Movement actigraphy from 3-axis/6-axis IMUs (accelerometers) and nocturnal PPG heart rate variability (HRV).
- **Connecting the Sensor**:
  When the device completes a sleep session:
  ```typescript
  // Post sleep epoch data:
  // { duration: 450, deep: 25, light: 50, rem: 20, awake: 5, score: 85 }
  ```
  The sleep cards automatically render the duration bars and score curves directly from these database entries.

### 6.3 Fall Detection Telemetry (`/fall-detection`)
- **Hardware Source**: Accelerometer & Gyroscope (e.g., MPU6050, LSM6DS3, BNO055).
- **Trigger Logic**: High-G acceleration impact spike (`> 3.0g`) immediately followed by an orientation angle change and a period of zero movement (inactivity).
- The microcontroller sends a fall event:
  `{ timestamp: "10:45 AM", severity: "High Severity", location: "Living Room" }`
- The `/fall-detection` screen immediately renders the new event card with its severity badge.

---

## 💾 7. Database & Persistence Layer

- **Database Path**: `data/vitality.db` (SQLite)
- **Initialized in**: `lib/db.ts`
- **Tables**:
  - `users`: User demographic data, location (`${city}, India`), and daily targets (`daily_steps_goal`, `daily_calories_goal`).
  - `health_data`: Timestamped sensor readings (`metric_type`, `value`, `recorded_at`).

### Instant UI Synchronization (`revalidatePath`)
Because Next.js uses React Server Components, running `revalidatePath('/dashboard')` or `revalidatePath('/sleep')` after inserting database records causes Next.js to re-fetch the fresh data on the server and stream it to the client with **zero page reload flicker**.

---

## 🤝 8. Daily Git Contribution Workflow

When working on a new feature or sensor integration:

1. **Pull the latest target branch**:
   ```bash
   git fetch origin
   git checkout <target-branch>
   git pull origin <target-branch>
   ```

2. **Create a descriptive feature branch**:
   ```bash
   git checkout -b feature/your-feature-name
   ```

3. **Validate TypeScript before staging**:
   ```bash
   npx tsc --noEmit
   ```
   *Make sure there are 0 compilation errors.*

4. **Commit with clean conventional messages**:
   ```bash
   git commit -m "feat(sensor): add ESP32 telemetry ingestion endpoint"
   ```

5. **Push and create a Pull Request**:
   ```bash
   git push origin feature/your-feature-name
   ```

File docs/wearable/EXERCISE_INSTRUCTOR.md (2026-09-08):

# Agent-controlled watch instructor

Status: built and checked on 2026-09-07; **not deployed or flashed**. The user
will explicitly say when to flash over OTA. Do not queue `pending_ota.txt`,
replace the laptop's gateway files, or restart its gateway before that.

Final OTA build ID: `369ba888`; application image: 2,068,608 bytes.

## Behavior

The Cerebras care agent selects an explicit `instructor` object alongside its
spoken response. The fields are `move`, `side` (anatomical left/right/both),
`pattern` (repeat/hold), and `period_seconds` (4–12). No keyword matching, IMU
motion, touch action, or playlist chooses a movement. A positive `hold_seconds`
sets its duration. Non-exercise sessions do not get the animation catalogue.

The watch shows a seated, shaded 3D instructor with teal sportswear, a stable
chair, depth-tested limbs and a fixed three-quarter camera. Six supported
movements are front arm raises to shoulder height, lateral raises to just below
shoulder height, elbow curls, shoulder rolls, seated marching, and torso turns.
Both-sided marching and turns alternate sides. Holds ease into a pose; shoulder
rolls must repeat. Unsupported instructions keep their existing voice behavior;
the agent is told to disclose that no matching visual exists.

Geometry references: [NHS sitting exercises](https://www.nhs.uk/live-well/exercise/sitting-exercises/)
and [North Tees chair exercises](https://www.nth.nhs.uk/resources/chair-exercises/).
These informed the seated posture, controlled arm movement and fixed hips during
turns. The animations are illustrative, not a clinically validated assessment
of a person's form. Wrist evidence remains separate from the demonstration.

## Ownership and timing

`care/instructor.py` defines the catalogue, model instructions and validation.
`care/agent.py` admits a demo only on a successful physical turn with a positive
hold, no question and a continuing session. It clears stale directives. The
chosen demo is saved with the transcript in `care/plan.py`; a forced form retry
replays that prior command, rather than a newly proposed different exercise.

`session.py` sends `exercise_instructor` events:

1. `prepare`: show the starting posture while Kiki speaks.
2. `start`: start motion after speech drains, for the timed hold only.
3. `stop`: close after the hold, cancellation, failure or session end.

Each command carries a unique `demo_id`. A start without its still-active
preparation is rejected. Stops for older demonstrations cannot close a newer
one. Speech-drain timeout suppresses the demo. Visual delivery errors are
best-effort and do not fail the spoken response. The local End session button
stops playback immediately and sends the existing care end action; the gateway
now also cancels its active speech/hold task on that action.
The button sends the urgent `cancel_turn` event first, so microphone backlog
cannot delay cancellation.

`kiki_instructor.cpp` owns an independent LVGL screen. It validates the wire
fields again and restores the normal screen on Stop, link loss, a fall check,
60-second preparation timeout or the animation deadline (at most 120 seconds).
The existing face-render timer yields while the instructor is visible.
`kiki_instructor_model.cpp/.hpp` contain the platform-independent 3D rig and
analytic ellipsoid renderer used by both the watch and the host preview.

The renderer allocates 587,520 bytes of colour/depth buffers in PSRAM only,
releases them when closed, and allocates nothing per frame. No new internal-RAM
frame buffers, graphics dependencies, asset downloads or network services.
Rendering runs on the LVGL timer at up to 10 fps and slows if a frame is costly.
Actual on-device frame rate and simultaneous audio remain to be checked after
the authorized OTA; host checks cannot establish those hardware properties.

## Verification and known baseline issue

- Full gateway suite: 489 tests pass, including 34 instructor tests for malformed
  output, speech/hold ordering, retries, cancellation and failed visual delivery.
- ESP-IDF firmware builds; the 5 MiB OTA slot has approximately 61% spare space.
- Host rig checks cover all six moves, both patterns, all sides, constant bone
  lengths, fixed hips, floor clearance, held poses and alternating marches.
- Existing panel-state, TX-priority, IMU-wire, protocol-frame, motion-classifier
  and dance-routine tests pass.
- Existing `test_fall_detector.cpp` fails its expectation that a worn 3g impact
  alone cannot trigger. The deployed detector explicitly allows such impacts.
  Both files are byte-identical to the laptop copies. No fall algorithm or
  thresholds were changed for the instructor.
- No live Cerebras request, physical display/audio test, gateway deployment or
  OTA has been performed for this change.

## Pending deployment

The prepared files are under `build/exercise-instructor-20260907/`. The package
contains the OTA image, the four required gateway files, checksums, previews,
and verification logs. The firmware and gateway changes should be deployed
together after the user authorizes flashing. New firmware understands the old
gateway; old firmware ignores these new events. Back up the running gateway
files and previous image before replacing them, preserve the existing
environment and care-state directory, and use the existing OTA workflow.

At inspection the gateway was PID 8147, managed by the laptop server manager,
listening on 8765. The inactive `kiki-esp32-gateway.service` and the root
`KikiESP32/gateway.log` were stale. Current log:
`/home/vaibhav/kiki_servers/logs/gateway.log`. Re-resolve the process at deployment.

Baseline laptop gateway SHA-256 values (verify again before replacement):

```
8fc5e9dadd956b779faa584e3dd65abf96262dc7e5fefc5cc2906e8def47e2b4  care/agent.py
98beca9c5508bb6ce32c500131c22f74a42340b24c9d588db6a269ecd3f3c74f  care/plan.py
c23563061c037675bc1f1003623a9448a11ee33781daac2171c6637cbd73e66f  session.py
```

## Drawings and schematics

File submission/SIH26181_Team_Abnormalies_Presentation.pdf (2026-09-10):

# Team ABNORMALIES

# SMART INDIA HACKATHON 2026

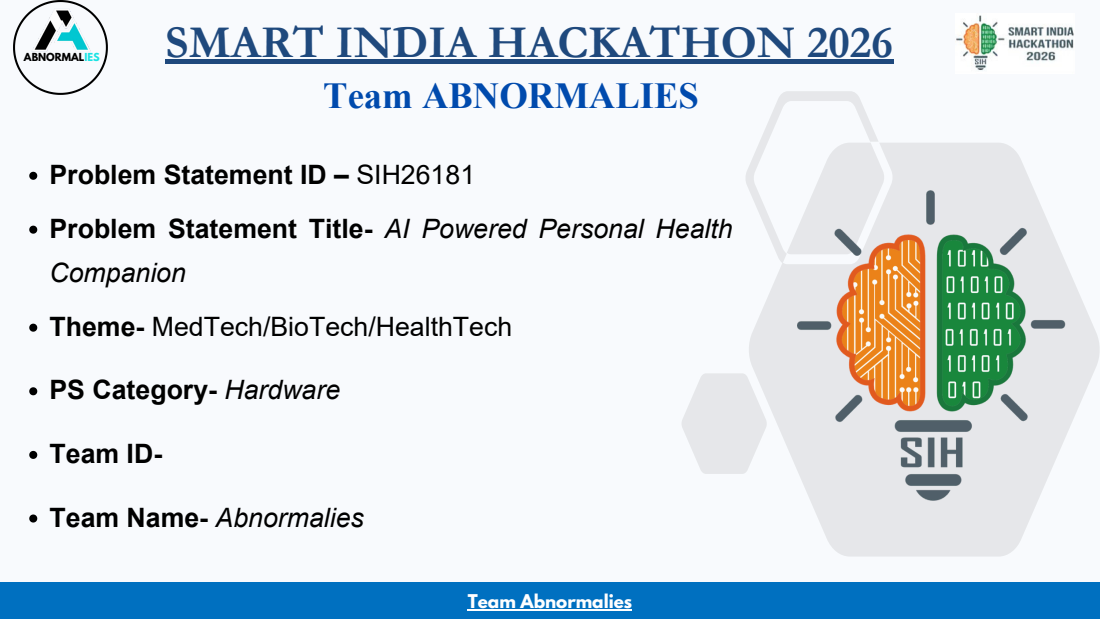
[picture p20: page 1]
Team ID-; Team Abnormalies; ABNORMALIES

Problem Statement ID – SIH26181
Problem Statement Title- AI Powered Personal Health
Companion
Theme- MedTech/BioTech/HealthTech

PS Category- Hardware

Team Name- Abnormalies

@SIH Idea submission- Template | 2

ABNORMALIES

Continuously monitors health and environmental signals.
Detects abnormal patterns and emerging health risks early.

### Provides personalized warnings before risks escalate into

emergencies.

### Supports users during heat waves, floods, pollution events and

other disasters.

## Voice-First, Edge AI for Disaster-Resilient Health Monitoring

# OUR IDEA

## A health companion you talk to. Kiki sits on your desk, learns your routine, remembers you, and answers out loud in about a second — English or Hindi. It watches your vitals and the air and heat around you, and speaks up before things get bad. The model doing the

talking runs on our own hardware.

# HOW IT ADDRESSES THE PROBLEM

PROPOSED SOLUTION | INNOVATION/UNIQUENESS A companion, with sub-second spoken replies, memory of past conversations, and a personality. No smartwatch does this.. Combines personal health data with real-time environmental risk context. Early-warning approach shifts healthcare from reactive response to preventive action.

# KIKI HEALTH COMPANION

Built from the very scratch by us

Video

# TECHNICAL APPROACH

TECHNOLOGIES | METHODOLOGY

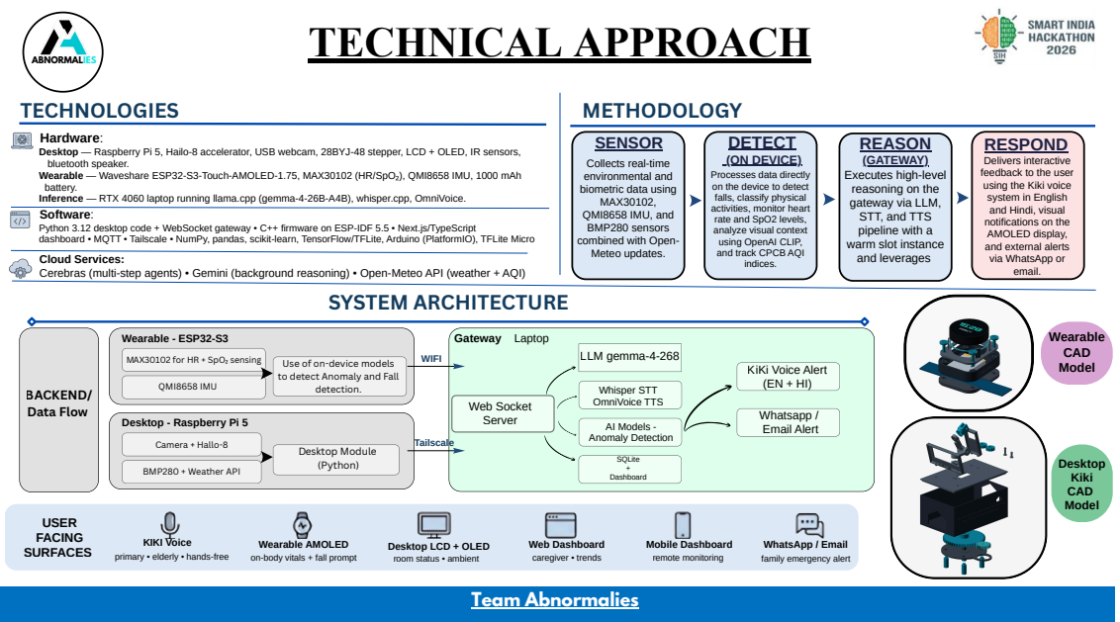
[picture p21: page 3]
ABNORMALIES; DETECT; OmniVoice TTS; AI Models - Anomaly Detection; SQLite + Dashboard; SYSTEM ARCHITECTURE; BACKEND/ Data Flow; Wearable - ESP32-S3; Gateway Laptop; USER FACING SURFACES; QMI8658 IMU; detection.; Camera + Hallo-8; BMP280 + Weather API; Desktop Module (Python); WIFI; Tailscale; Web Socket Server; Whatsapp / Email Alert; KIKI Voice primary • elderly • hands-free; Wearable AMOLED on-body vitals + fall prompt; room status • ambient; caregiver • trends Web Dashboard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

Hardware:
Desktop — Raspberry Pi 5, Hailo-8 accelerator, USB webcam, 28BYJ-48 stepper, LCD + OLED, IR sensors,
bluetooth speaker.
Wearable — Waveshare ESP32-S3-Touch-AMOLED-1.75, MAX30102 (HR/SpO₂), QMI8658 IMU, 1000 mAh
battery.
Inference — RTX 4060 laptop running llama.cpp (gemma-4-26B-A4B), whisper.cpp, OmniVoice.
Software:
Python 3.12 desktop code + WebSocket gateway • C++ firmware on ESP-IDF 5.5 • Next.js/TypeScript
dashboard • MQTT • Tailscale • NumPy, pandas, scikit-learn, TensorFlow/TFLite, Arduino (PlatformIO), TFLite Micro
Cloud Services:
Cerebras (multi-step agents) • Gemini (background reasoning) • Open-Meteo API (weather + AQI)

SENSOR
(ON DEVICE) Collects real-time
environmental and
biometric data using
MAX30102,
QMI8658 IMU, and
BMP280 sensors
combined with Open-
Meteo updates.

REASON
(GATEWAY)
Executes high-level
reasoning on the
gateway via LLM,
STT, and TTS
pipeline with a
warm slot instance
and leverages

RESPOND
Delivers interactive
feedback to the user
using the Kiki voice
system in English
and Hindi, visual
notifications on the
AMOLED display,
and external alerts
via WhatsApp or
email.

Processes data directly
on the device to detect
falls, classify physical
activities, monitor heart
rate and SpO2 levels,
analyze visual context
using OpenAI CLIP,
and track CPCB AQI
indices.

LLM gemma-4-268 Whisper STT

MAX30102 for HR + SpO₂ sensing

Use of on-device models
to detect Anomaly and Fall

KiKi Voice Alert

Desktop - Raspberry Pi 5

Desktop LCD + OLED

# FEASIBILITY AND VIABILITY

ABNORMALIES

TECHNICAL FEASIBILITY | CHALLENGES & RISKS
Multi-source monitoring: Wearable sensors for heart rate,
SpO₂ and body temperature.

### Integrated system: Wearable, camera (chatbot) and mobile dashboard

work together.

### Real-time alerts: Detects abnormalities and provides personalized

guidance.
Prototype-ready: Uses available hardware and software components. MITIGATION STRATEGIES Sensor calibration and signal filtering: Calibrate during setup and apply filtering to reduce movement-related noise. Warm prompt cache: After every reply the whole conversation is prefilled back, so a follow-up costs ~10 tokens. Lightweight edge models: Optimize and compress (quants,mtp) models for faster, real-time inference. Multi-reading confirmation: Use consecutive readings and threshold checks before triggering critical alerts. | IMPLEMENTATION VIABILITY

### Sensor accuracy and calibration:Heart rate and SpO₂ readings may vary with movement, placement

and skin contact.
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

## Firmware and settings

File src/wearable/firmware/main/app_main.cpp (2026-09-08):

#include "audio_pipeline.hpp"
#include "gateway_client.hpp"
#include "kiki_ota.hpp"
#include "kiki_power.hpp"
#include "kiki_time.hpp"
#include "kiki_exercise.hpp"
#include "kiki_wearable.hpp"
#include "kiki_dance.hpp"
#include "kiki_log.hpp"
#include "kiki_motion.hpp"
#include "kiki_setup.hpp"
#include "kiki_settings.hpp"
#include "kiki_ui.hpp"
#include "protocol.hpp"
#include "wifi_station.hpp"

#include <algorithm>
#include <atomic>

#include <cstdio>
#include <cstring>
#include "bsp/esp-bsp.h"
#include "esp_app_desc.h"
#include "esp_check.h"
#include "esp_heap_caps.h"
#include "esp_log.h"
#include "esp_system.h"
#include "esp_timer.h"
#include "freertos/FreeRTOS.h"
#include "freertos/queue.h"
#include "freertos/task.h"
#include "nvs_flash.h"

namespace {
constexpr char kTag[] = "kiki_main";

const char *reset_reason_name(esp_reset_reason_t reason) {
    switch (reason) {
        case ESP_RST_POWERON: return "power-on";
        case ESP_RST_EXT: return "external-pin";
        case ESP_RST_SW: return "software";
        case ESP_RST_PANIC: return "panic";
        case ESP_RST_INT_WDT: return "interrupt-watchdog";
        case ESP_RST_TASK_WDT: return "task-watchdog";
        case ESP_RST_WDT: return "watchdog";
        case ESP_RST_DEEPSLEEP: return "deep-sleep";
        case ESP_RST_BROWNOUT: return "brownout";
        case ESP_RST_SDIO: return "sdio";
        case ESP_RST_UNKNOWN:
        default: return "unknown";
    }
}

constexpr size_t kMicSamples = 512;
constexpr size_t kMicQueueDepth = 64;
struct MicPacket {
    int16_t samples[kMicSamples];
    uint16_t count;
    uint16_t sample_rate;
    uint8_t flags;
    uint32_t sequence;
    int64_t timestamp_us;
};
QueueHandle_t g_mic_queue = nullptr;
TaskHandle_t g_tx_task = nullptr;

void microphone_frame(const int16_t *samples, size_t count, uint32_t sample_rate,
                      uint8_t flags, uint32_t sequence, int64_t timestamp_us) {
    if (!g_mic_queue || !samples || count == 0 || count > kMicSamples ||
        sample_rate > UINT16_MAX) return;
    MicPacket packet{};
    memcpy(packet.samples, samples, count * sizeof(int16_t));
    packet.count = static_cast<uint16_t>(count);
    packet.sample_rate = static_cast<uint16_t>(sample_rate);
    packet.flags = flags;
    packet.sequence = sequence;
    packet.timestamp_us = timestamp_us;
    if (xQueueSend(g_mic_queue, &packet, 0) != pdTRUE) {
        static uint32_t drops = 0;
        if ((++drops % 100) == 1) ESP_LOGW(kTag, "microphone network queue full");
        return;
    }
    // The tx task sleeps on this notification rather than polling, so a frame
    // and a button press both wake it immediately.
    if (g_tx_task) xTaskNotifyGive(g_tx_task);
}

// Above this many frames waiting, the uplink is not keeping up and the backlog
// is thrown away rather than sent. AEC output is normally 32 ms per frame, so
// twelve frames cap stale audio near 384 ms instead of consuming half the
// queue.
constexpr UBaseType_t kMicBacklogDrop = 12;

// --- Uplink gating on a remote link ---------------------------------------
//
// Kiki uploads 16 kHz mono microphone audio continuously -- ~256 kbps, all the
// time, whether or not anyone is speaking, because the wake word is found in
// the transcript rather than in the audio. On the LAN that is free. On a phone
// hotspot or a contended college AP it is the whole problem: the moment the
// radio has a bad second the socket's send cannot complete, and
// esp_websocket_client treats a short write as fatal and aborts the entire
// connection (§8). Observed on 2026-08-18: sessions lasting 3.7 s to 280 s,
// dropping with `rcvd=None sent=None` or a keepalive timeout, with the mic
// stream reading a healthy 1.00x right up to the moment it died -- not
// congestion building, a single stall killing a session.
//
// So on a remote link that has *shown* it cannot hold the stream, the board
// sends audio around *speech* instead of continuously, using the device VAD it
// already computes for barge-in. A quiet room then costs almost nothing.
//
// "Has shown" is the important part, and it is why this is not simply on for
// every remote link: the same board on stable wifi far from home, through the
// same tunnel, runs for hours without a drop. The trigger is evidence, not
// geography -- one send that takes over a second, or one session already lost
// this boot. A good link never engages it; a hotspot engages it within a
// minute and keeps working.
//
// Three things keep this from making Kiki deaf, which would be a much worse
// bug than a reconnect:
//   * it only applies when the frame is AEC-processed, i.e. the DSP path that
//     produces the VAD vote is actually running. A raw fallback frame carries
//     no vote and is always sent.
//   * a preroll of the frames just before speech starts is flushed on the way
//     open, so the first syllable of "kiki" is never clipped.
//   * a short burst goes out every ten seconds regardless, so a VAD that is
//     systematically missing quiet speech shows up as thin ambient capture
//     rather than as silence nobody can explain.
constexpr int64_t kUplinkHangoverUs = 2000000;      // keep sending after speech
constexpr int64_t kUplinkBurstPeriodUs = 10000000;  // ...and a little anyway
constexpr int64_t kUplinkBurstLengthUs = 500000;
constexpr size_t kPrerollFrames = 12;               // ~384 ms at 32 ms a frame

// A frame carries 32 ms of audio. A send that takes eight times that long is
// not a busy moment: while it is in flight the client mutex is held, so nothing
// is being read from the socket and no keepalive can go out. The old threshold
// was 1.2 s, which is well past the point where the session is already lost.
constexpr int64_t kSlowSendUs = 250000;
constexpr int64_t kFastSendUs = 50000;
// How long to stop feeding a stalled uplink. Short to begin with, because a
// closed gate is speech nobody hears; doubling, because a link that stalls
// repeatedly is not going to be talked round.
constexpr int64_t kUplinkBackoffMinUs = 500000;
constexpr int64_t kUplinkBackoffMaxUs = 4000000;

MicPacket *g_preroll = nullptr;                     // PSRAM ring
size_t g_preroll_head = 0;
size_t g_preroll_count = 0;
int64_t g_speech_until_us = 0;
int64_t g_burst_started_us = 0;
bool g_uplink_open = true;
int64_t g_uplink_closed_until_us = 0;
int64_t g_uplink_backoff_us = kUplinkBackoffMinUs;

void remember_preroll(const MicPacket &packet) {
    if (!g_preroll) {
        // PSRAM, not internal: internal RAM is the scarce pool on this board
        // and 12 KiB of it is a display flush.
        g_preroll = static_cast<MicPacket *>(
            heap_caps_malloc(sizeof(MicPacket) * kPrerollFrames, MALLOC_CAP_SPIRAM));
        if (!g_preroll) return;
    }
    g_preroll[g_preroll_head] = packet;
    g_preroll_head = (g_preroll_head + 1) % kPrerollFrames;
    if (g_preroll_count < kPrerollFrames) ++g_preroll_count;
}

void flush_preroll() {
    if (!g_preroll || g_preroll_count == 0) return;
    const size_t first = (g_preroll_head + kPrerollFrames - g_preroll_count) % kPrerollFrames;
    for (size_t i = 0; i < g_preroll_count; ++i) {
        const MicPacket &packet = g_preroll[(first + i) % kPrerollFrames];
        kiki::gateway_client_send_mic(packet.samples, packet.count, packet.sample_rate,
                                      packet.flags, packet.sequence, packet.timestamp_us);
    }
    g_preroll_count = 0;
}

// Thrifty is now the DEFAULT on a remote link rather than something the board
// switches on after it has already lost a session. The old rule -- wait for
// evidence, then latch for the rest of the boot -- got both halves wrong: the
// evidence only ever arrives *after* the first session dies, and a latch means
// a link that recovers never gets its ambient capture back. This is a decision
// per link, not per boot.
//
// It is still not the real fix, and it is not meant to be: gating exists only
// because a 32 ms frame currently costs 1 KiB on the wire. Once that frame is
// ~96 bytes of Opus, continuous capture fits on any of these links and this
// gate can go back to being what it was written as -- an emergency measure.
std::atomic<bool> g_uplink_thrifty{false};

void note_uplink_trouble(const char *why) {
    const int64_t now = esp_timer_get_time();
    if (!g_uplink_thrifty.exchange(true)) {
        ESP_LOGW(kTag, "uplink is marginal (%s); sending microphone audio "
                       "around speech from now on", why);
    }
    g_uplink_closed_until_us = now + g_uplink_backoff_us;
    g_uplink_backoff_us = std::min(g_uplink_backoff_us * 2, kUplinkBackoffMaxUs);
}

// A send that completed promptly is the only evidence the link recovered, so
// recovery is measured, not assumed -- and unlike the old latch it is
// reversible, which is what lets a board that walked back into good Wi-Fi start
// listening properly again without a reboot.
void note_uplink_healthy() {
    if (g_uplink_backoff_us > kUplinkBackoffMinUs) {
        g_uplink_backoff_us = std::max(kUplinkBackoffMinUs, g_uplink_backoff_us / 2);
    }
}

bool uplink_wants(const MicPacket &packet) {
    if (!kiki::gateway_client_is_remote()) return true;
    if (!g_uplink_thrifty.load()) {
        // A remote link starts thrifty. One lost session used to be the
        // trigger; now it is simply being remote, because every remote link
        // this board has met has been the one that could not hold the stream.
        note_uplink_trouble("a remote link");
    }
    if (kiki::ui_talk_held()) return true;      // a silent hold is still a turn
    const int64_t now = esp_timer_get_time();
    // The link is stalled. Feeding it is what turns a stall into a dropped
    // session, and the frames sent during one are the frames that push it over.
    if (now < g_uplink_closed_until_us) return false;
    if (!(packet.flags & kiki::AudioFlags::AecProcessed)) return true;
    if (packet.flags & kiki::AudioFlags::DeviceVadSpeech) {
        g_speech_until_us = now + kUplinkHangoverUs;
    }
    if (now < g_speech_until_us) return true;
    if (now - g_burst_started_us >= kUplinkBurstPeriodUs) g_burst_started_us = now;
    return now - g_burst_started_us < kUplinkBurstLengthUs;
}

void microphone_network_task(void *) {
    MicPacket packet{};
    while (true) {
        // Control before audio, every time round. This is the ordering that
        // makes a button press feel instant on a congested link: the press does
        // not queue behind a second of microphone PCM, it overtakes it.
        while (kiki::gateway_client_flush_events()) {
        }
        if (xQueueReceive(g_mic_queue, &packet, 0) != pdTRUE) {
            // Nothing to do. Sleep until a frame or an event is queued; the
            // timeout is only insurance against a missed notification.
            ulTaskNotifyTake(pdTRUE, pdMS_TO_TICKS(100));
            continue;
        }
        if (!kiki::gateway_client_connected()) continue;
        // Raw microphone audio remains fail-closed during playback. Only the
        // ESP-SR output explicitly marked AEC-cleaned may reach the gateway;
        // an AEC allocation/configuration failure therefore cannot make Kiki
        // wake herself up.
        if (kiki::audio_pipeline_is_playing() &&
            (!kiki::settings_barge_in_enabled() ||
             !(packet.flags & kiki::AudioFlags::AecProcessed))) continue;
        // Nothing competes with a firmware download. 768 kbps of ambient audio
        // sharing the uplink with a 1.8 MB fetch is why the LAN update stalled
        // at 0% for sixteen seconds and took three times longer than the same
        // image did over the tunnel -- where the talk-button gate had already
        // silenced the microphone by accident. An update is seconds of work and
        // ends in a reboot; there is nothing to hear in the meantime.
        if (kiki::ota_in_progress()) continue;
        // Shed congestion HERE, never by letting the send time out. A short
        // write makes esp_websocket_client abort the connection outright, so a
        // slow uplink used to become a dropped session every few minutes; a
        // discarded microphone frame is just a discarded frame. Sequence
        // numbers still advance, so the gateway sees a real audio_gap rather
        // than silently mistaking the backlog for continuous speech.
        if (uxQueueMessagesWaiting(g_mic_queue) > kMicBacklogDrop) {
            static uint32_t shed = 0;
            if ((++shed % 100) == 1) {
                ESP_LOGW(kTag, "uplink behind; shedding microphone backlog");
            }
            continue;
        }
        if (!uplink_wants(packet)) {
            remember_preroll(packet);
            g_uplink_open = false;
            continue;
        }
        if (!g_uplink_open) {
            // Opening: the syllable that woke the VAD started before it fired.
            flush_preroll();
            g_uplink_open = true;
        }
        // Timed, because how long a send takes is the only early warning there
        // is. While this call is inside the client mutex the websocket task
        // cannot read the socket and cannot answer a PING, so a send that took
        // a quarter of a second has already cost Kiki audio and may cost the
        // session.
        const int64_t send_started_us = esp_timer_get_time();
        kiki::gateway_client_send_mic(packet.samples, packet.count, packet.sample_rate,
                                      packet.flags, packet.sequence, packet.timestamp_us);
        const int64_t took_us = esp_timer_get_time() - send_started_us;
        if (took_us > kSlowSendUs) note_uplink_trouble("a slow send");
        else if (took_us < kFastSendUs) note_uplink_healthy();
    }
}


void playback_drained() { kiki::gateway_client_send_event("playback_drained"); }
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
extern "C" void app_main(void) {
    const esp_reset_reason_t boot_reset_reason = esp_reset_reason();
    esp_err_t nvs = nvs_flash_init();
    if (nvs == ESP_ERR_NVS_NO_FREE_PAGES || nvs == ESP_ERR_NVS_NEW_VERSION_FOUND) {
        ESP_ERROR_CHECK(nvs_flash_erase());
        nvs = nvs_flash_init();
    }
    ESP_ERROR_CHECK(nvs);
    kiki::settings_init();
    kiki::ui_start();
    // Shown before anything else can fail. Without a serial console there is
    // otherwise no way to answer "did the flash actually take?" -- the build
    // stamp changes every build, so a stale screen is obvious at a glance.
    {
        // The build ID is the first four bytes of the ELF SHA-256, NOT the
        // compile date. esp_app_desc.c is not always recompiled, so its date
        // and time can be hours stale while the code around them is current --
        // which made the panel claim an old build after a correct flash, and
        // sent us chasing a download that was never wrong. The ELF hash is
        // recomputed at every link, so it cannot lie about what is running.
        const esp_app_desc_t *app = esp_app_get_description();
        char stamp[40];
        std::snprintf(stamp, sizeof(stamp), "build %02x%02x%02x%02x",
                      app->app_elf_sha256[0], app->app_elf_sha256[1],
                      app->app_elf_sha256[2], app->app_elf_sha256[3]);
        ESP_LOGW(kTag, "Kiki %s (%s, esp_app_desc date %s %s)", stamp, app->version,
                 app->date, app->time);
        kiki::ui_set_lcd("Kiki", stamp);
    }
    kiki::ui_set_state("connecting");
    ESP_LOGI(kTag, "display and touch ready");
    // 64 slots of just over a kilobyte each is 66 KiB. That came out of the
    // ~166 KiB of internal heap this app actually has, in direct competition
    // display's DMA buffers; PSRAM has megabytes spare and the queue is never
    // touched from an ISR.
    g_mic_queue = xQueueCreateWithCaps(kMicQueueDepth, sizeof(MicPacket), MALLOC_CAP_SPIRAM);
    ESP_ERROR_CHECK(g_mic_queue ? ESP_OK : ESP_ERR_NO_MEM);
    xTaskCreatePinnedToCore(microphone_network_task, "kiki_net_tx", 6144, nullptr, 17,
                            &g_tx_task, 0);
    kiki::gateway_client_set_tx_task(g_tx_task);
    // Internal RAM is the scarce resource on this board (~166 KiB of heap), and the
    // display's SPI driver competes for the DMA-capable part of it on every
    // flush. Print both pools so a "Failed to allocate priv TX buffer" flood is
    // one line away from being explained.
    ESP_LOGI(kTag, "heap: internal %u free (%u largest DMA), psram %u free",
             static_cast<unsigned>(heap_caps_get_free_size(MALLOC_CAP_INTERNAL)),
             static_cast<unsigned>(heap_caps_get_largest_free_block(MALLOC_CAP_DMA)),
             static_cast<unsigned>(heap_caps_get_free_size(MALLOC_CAP_SPIRAM)));
    ESP_LOGI(kTag, "starting audio codecs");
    kiki::power_init();
    ESP_ERROR_CHECK(kiki::audio_pipeline_start(microphone_frame, playback_drained));
    ESP_LOGI(kTag, "audio codecs ready");
    // Physical personality is deliberately non-fatal and starts before Wi-Fi:
    // the face can still react offline, while the state gate suppresses motion
    // comedy during provisioning and boot screens.
    const esp_err_t motion_result = kiki::motion_start();
    if (motion_result != ESP_OK) {
        ESP_LOGW(kTag, "motion reactions unavailable: %s", esp_err_to_name(motion_result));
    }
    // Blocks on the panel when no network is provisioned or the saved one is
    // gone. Audio is already running, so the codecs are warm by the time the
    // user finishes typing.
    // Armed BEFORE the join, not after it.
    //
    // The watchdog reverts to the previous image unless this one reaches the
    // gateway within three minutes, and the case that matters most is a build
    // that cannot get onto Wi-Fi at all. `setup_ensure_wifi()` handles that by
    // showing the provisioning panel and waiting forever, so arming afterwards
    // meant the one failure the watchdog exists for was the one failure it
    // could never see: the board would sit on the setup screen, on the bad
    // image, until somebody found a USB cable. Arming here costs nothing --
    // `is_pending()` is false unless this image arrived by OTA -- and the
    // display is already up, because the panel below draws on it.
    kiki::ota_arm_rollback_watchdog();
    ESP_ERROR_CHECK(kiki::setup_ensure_wifi());
    kiki::ui_show();
    ESP_LOGI(kTag, "Wi-Fi connected");
    // Before the gateway, because the gateway may need TLS and TLS needs a
    // real date. Blocking is the point: a wss:// attempt made while the clock
    // still says 1970 fails certificate validation and looks like a network
    // fault instead of a clock fault.
    if (!kiki::time_sync(8000)) kiki::time_sync_keep_trying();
    ESP_ERROR_CHECK(kiki::gateway_client_start());
    const esp_err_t wearable_result = kiki::wearable_start();
    if (wearable_result != ESP_OK) {
        ESP_LOGW(kTag, "wearable health unavailable: %s",
                 esp_err_to_name(wearable_result));
    }
    // Health mode's motion capture. Non-fatal, like motion and wearable: it
    // records nothing until a gateway in health mode asks for a window, so a
    // failure here costs only the guided-exercise feature.
    const esp_err_t exercise_result = kiki::exercise_start();
    if (exercise_result != ESP_OK) {
        ESP_LOGW(kTag, "guided-exercise capture unavailable: %s",
                 esp_err_to_name(exercise_result));
    }
    kiki::log_remote_start();
    // Startup UART often disappears with the reset itself. Repeat this after
    // remote logging is armed so the next unexpected reboot is diagnosable
    // from the laptop without attaching a serial monitor first.
    ESP_LOGW(kTag, "boot reset reason: %s (%d)",
             reset_reason_name(boot_reset_reason),
             static_cast<int>(boot_reset_reason));
    // 4096 was survivable while the stats payload was small. It is not a
    // number to leave at the edge: this task calls build_event, which does
    // std::string concatenation, and every field added to device_stats pushes
    // it further. Reported as telemetry_stack_free in the payload it builds.
    xTaskCreatePinnedToCore(telemetry_task, "kiki_telemetry", 6144, nullptr, 2, nullptr, 0);
    ESP_LOGI(kTag, "Kiki ESP32 started; gateway=%s", CONFIG_KIKI_GATEWAY_URI);
}

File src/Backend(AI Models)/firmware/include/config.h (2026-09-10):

// config.h -- all tunable constants for the health telemetry pipeline.
// Values correspond directly to the executable spec (sections referenced in comments).
#ifndef CONFIG_H
#define CONFIG_H

// ---- Sampling rates (spec §1) ----
#define IMU_FS_HZ         50
#define VITALS_FS_HZ      1
#define IMU_WINDOW_S      1.0f         // window used for activity-tree features
#define IMU_WINDOW_LEN    (IMU_FS_HZ * (int)IMU_WINDOW_S)   // 50 samples

// ---- Bootstrap / cold-start (spec §2) ----
#define BOOTSTRAP_PHASE0_S        (5 * 60)     // 0-5min: population prior only
#define BOOTSTRAP_PHASE1_TARGET_N 500          // samples until fully personalized
#define PERSISTENCE_SAMPLES       3            // consecutive samples required to confirm an anomaly

// Population-prior gross thresholds used during Phase 0
#define POP_HR_LOW      50.0f
#define POP_HR_HIGH     100.0f
#define POP_HR_GROSS_HIGH 140.0f   // alert even in phase 0 if exceeded at rest
#define POP_SPO2_LOW     95.0f
#define POP_SPO2_GROSS_LOW 90.0f

// ---- Dual-timescale baseline (spec §3) ----
#define BASELINE_SHORT_WINDOW_S   (30 * 60)    // 30 min
#define BASELINE_LONG_WINDOW_S    (14 * 24 * 3600) // 14 days
#define ACUTE_ANOMALY_SIGMA       2.5f
#define TREND_ANOMALY_SIGMA       1.5f
#define TREND_SUSTAIN_S           (6 * 3600)   // 6 hours

// ---- Activity classes (spec §4/§6) ----
#define NUM_ACTIVITY_STATES 5   // Resting, Inactive, Walking, Running, Transition
#define ACTIVITY_CONFIDENCE_LOW 0.7f
#define LOW_CONFIDENCE_SIGMA_WIDEN 3.5f   // used instead of ACUTE_ANOMALY_SIGMA when confidence is low

// ---- PPG motion-artifact gate (spec §5) ----
// Acceleration-variance threshold above which HR/SpO2 samples are treated as low-confidence.
// Tuned per activity state; index matches activity_t enum order in activity_tree.h.
static const float MOTION_GATE_THRESHOLD[NUM_ACTIVITY_STATES] = {
    0.05f,   // Inactive
    0.10f,   // Resting
    0.60f,   // Running
    0.35f,   // Transition
    0.40f,   // Walking
};

// ---- Fall detection (spec §7/§8) ----
#define FALL_PROB_THRESHOLD        0.8f
#define FALL_CONFIRM_WINDOW_S      5
#define FALL_STILLNESS_ACC_TOL     0.05f   // |acc_mag - 1.0g| below this counts as "still"
#define FALL_STILLNESS_GYRO_TOL    3.0f    // deg/s
#define FALL_STILLNESS_MIN_S       3       // consecutive seconds of stillness to confirm

// ---- TFLite Micro tensor arena (spec §9 -- measure actual usage with
// tflite::RecordingMicroAllocator during bring-up and adjust) ----
#define TENSOR_ARENA_SIZE (60 * 1024)

// ---- Risk scoring ----
#define RISK_LOW_MAX      33
#define RISK_MED_MAX      66

// ---- Serial / debug ----
#define SERIAL_BAUD 115200

// ---- WiFi + FastAPI push endpoint ----
// Fill in your real WiFi credentials below. Do NOT use 127.0.0.1/localhost --
// that refers to the ESP32 itself, not your PC.
#define WIFI_SSID        "Redmi Note 10 Pro"
#define WIFI_PASSWORD    "ejehdmcgka75yvd"
#define FASTAPI_ENDPOINT "http://192.168.29.96:8000/telemetry"

#endif // CONFIG_H

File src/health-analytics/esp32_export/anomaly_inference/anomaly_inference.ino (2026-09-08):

/*
  anomaly_inference.ino
  -----------------------
  Runs the tiny autoencoder anomaly-detection model on an ESP32 using the
  Chirale TensorFlow Lite for Microcontrollers Arduino library.

  What this sketch does each cycle:
    1. Reads heart_rate + steps_in_interval from your sensor code (stubbed
       here -- replace read_heart_rate()/read_steps_in_interval() with your
       actual MAX30102 / accelerometer driver calls).
    2. Normalizes features using the mean/std from models/feature_scaler.json.
    3. Runs the int8 quantized model, computes reconstruction error.
    4. Compares against the threshold from feature_scaler.json.
    5. If it fires, this is a SECONDARY signal -- the primary anomaly
       detector on real deployments should still be the cheap rule-based
       z-score check (baseline.py / anomaly_detection.py ported to C),
       run every sample. This model only needs to run periodically
       (e.g. once per minute) since it's checking a joint pattern, not a
       fast physiological event.
*/

// include main library header file
#include <Chirale_TensorFlowLite.h>

// include static array definition of pre-trained model
#include "model_data.h"

// This TensorFlow Lite Micro Library for Arduino is not similar to standard
// Arduino libraries. These additional header files must be included.
#include "tensorflow/lite/micro/all_ops_resolver.h"
#include "tensorflow/lite/micro/micro_interpreter.h"
#include "tensorflow/lite/schema/schema_generated.h"

// ---- From models/feature_scaler.json (already filled in) ----
const float FEATURE_MEAN[4] = {81.73676300048828f, 21.029739379882812f, -0.0008795579196885228f, -1.3366488019528333e-05f};
const float FEATURE_STD[4]  = {17.400503158569336f, 32.469749450683594f, 0.7074612975120544f, 0.7067485451698303f};
const float ANOMALY_THRESHOLD = 0.9876211881637573f;

// Globals pointers, used to address TensorFlow Lite components.
const tflite::Model* model = nullptr;
tflite::MicroInterpreter* interpreter = nullptr;
TfLiteTensor* input = nullptr;
TfLiteTensor* output = nullptr;

// There is no way to calculate this parameter
// the value is usually determined by trial and errors
// It is the dimension of the memory area used by the TFLite interpreter
// to store tensors and intermediate results
constexpr int kTensorArenaSize = 8 * 1024;  // tiny model -> tiny arena

// Keep aligned to 16 bytes for CMSIS (Cortex Microcontroller Software Interface Standard)
alignas(16) uint8_t tensor_arena[kTensorArenaSize];

float read_heart_rate() { return 72.0f; }   // TODO: wire to real sensor
int read_steps_in_interval() { return 12; } // TODO: wire to real sensor

void setup() {
  // Initialize serial communications and wait for Serial Monitor to be opened
  Serial.begin(115200);
  while(!Serial);

  Serial.println("Anomaly Detection Inference Example");
  Serial.println("Initializing TensorFlow Lite Micro Interpreter...");

  // Map the model into a usable data structure. This doesn't involve any
  // copying or parsing, it's a very lightweight operation.
  model = tflite::GetModel(g_anomaly_autoencoder_model);

  // Check if model and library have compatible schema version,
  // if not, there is a misalignement between TensorFlow version used
  // to train and generate the TFLite model and the current version of library
  if (model->version() != TFLITE_SCHEMA_VERSION) {
    Serial.println("Model provided and schema version are not equal!");
    while(true); // stop program here
  }

  // This pulls in all the TensorFlow Lite operators.
  static tflite::AllOpsResolver resolver;

  // Build an interpreter to run the model with.
  static tflite::MicroInterpreter static_interpreter(
      model, resolver, tensor_arena, kTensorArenaSize);
  interpreter = &static_interpreter;

  // Allocate memory from the tensor_arena for the model's tensors.
  // if an error occurs, stop the program.
  TfLiteStatus allocate_status = interpreter->AllocateTensors();
  if (allocate_status != kTfLiteOk) {
    Serial.println("AllocateTensors() failed");
    while(true); // stop program here
  }

  // Obtain pointers to the model's input and output tensors.
  input = interpreter->input(0);
  output = interpreter->output(0);

  Serial.println("Initialization done.");
  Serial.println("");
}

void loop() {
  float hr = 180.0f;
  int steps = read_steps_in_interval();

  unsigned long now_ms = millis();
  float hour_of_day = (now_ms / 3600000.0f);  // replace with RTC-based hour
  float hour_sin = sin(2.0f * PI * hour_of_day / 24.0f);
  float hour_cos = cos(2.0f * PI * hour_of_day / 24.0f);

  float raw[4] = {hr, (float)steps, hour_sin, hour_cos};
  float normalized[4];
  for (int i = 0; i < 4; i++) {
    normalized[i] = (raw[i] - FEATURE_MEAN[i]) / FEATURE_STD[i];
  }

  // Quantize the input from floating-point to integer
  // because model has been optimized by quantization
  float in_scale = input->params.scale;
  int in_zero = input->params.zero_point;
  for (int i = 0; i < 4; i++) {
    int32_t q = (int32_t)roundf(normalized[i] / in_scale) + in_zero;
    input->data.int8[i] = (int8_t)constrain(q, -128, 127);
  }

  // Run inference, and report if an error occurs
  TfLiteStatus invoke_status = interpreter->Invoke();
  if (invoke_status != kTfLiteOk) {
    Serial.println("Invoke failed!");
    return;
  }

  // Obtain the quantized output from model's output tensor
  // and dequantize to floating-point
  float out_scale = output->params.scale;
  int out_zero = output->params.zero_point;
  float mse = 0.0f;
  for (int i = 0; i < 4; i++) {
    float recon = (output->data.int8[i] - out_zero) * out_scale;
    float diff = recon - normalized[i];
    mse += diff * diff;
  }
  mse /= 4.0f;

  // Print current status
  Serial.print("HR: ");
  Serial.print(hr, 1);
  Serial.print(", Steps: ");
  Serial.print(steps);
  Serial.print(", MSE: ");
  Serial.println(mse, 4);
  
  // Check for anomaly
  if (mse > ANOMALY_THRESHOLD) {
    Serial.print("⚠️ Joint-pattern anomaly flagged, reconstruction_error=");
    Serial.println(mse, 4);
    // TODO: surface this alongside the rule-based anomaly flag, not instead of it.
  }

  delay(60000);  // run this check once a minute
}

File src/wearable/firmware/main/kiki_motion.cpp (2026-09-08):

#include "kiki_motion.hpp"

#include <algorithm>
#include <atomic>
#include <cmath>
#include <cstdio>
#include <cstring>

#include "audio_pipeline.hpp"
#include "bsp/esp-bsp.h"
#include "esp_log.h"
#include "esp_timer.h"
#include "freertos/FreeRTOS.h"
#include "freertos/queue.h"
#include "freertos/task.h"
#include "gateway_client.hpp"
#include "kiki_dance.hpp"
#include "kiki_ui.hpp"
#include "kiki_exercise.hpp"
#include "kiki_wearable.hpp"
#ifdef M_PI
#undef M_PI
#endif
#include "qmi8658.h"

namespace kiki {
namespace {

constexpr char kTag[] = "kiki_motion";
constexpr float kMetersPerSecondSquaredPerG = 9.80665F;
constexpr uint32_t kSamplePeriodMs = 20;  // 50 Hz classifier input

qmi8658_dev_t g_imu{};
QueueHandle_t g_reaction_queue = nullptr;
std::atomic<bool> g_available{false};
std::atomic<bool> g_context_idle{false};
std::atomic<bool> g_context_music{false};
std::atomic<bool> g_charging{false};
std::atomic<bool> g_low_battery{false};
std::atomic<uint32_t> g_activity_sequence{0};
portMUX_TYPE g_stats_mux = portMUX_INITIALIZER_UNLOCKED;
MotionRuntimeStats g_stats{};

struct ReactionSpec {
    const char *face;
    const char *detail;
    LocalEffect effect;
    uint32_t duration_ms;
    bool critical;
};

ReactionSpec reaction_for(MotionSituation situation) {
    switch (situation) {
        case MotionSituation::PickedUp:
            return {"surprised", "picked up", LocalEffect::Pickup, 1500, false};
        case MotionSituation::UprightAlert:
            return {"motion_alert", "upright", LocalEffect::Alert, 2600, false};
        case MotionSituation::FaceDown:
            return {"motion_face_down", "face down", LocalEffect::FaceDown, 3800, false};
        case MotionSituation::UpsideDown:
            return {"motion_upside_down", "upside down", LocalEffect::UpsideDown, 3600, false};
        case MotionSituation::Sideways:
            return {"sleepy", "sideways", LocalEffect::Sleepy, 2800, false};
        case MotionSituation::GentleWiggle:
            return {"giggle", "wiggle", LocalEffect::Wiggle, 1900, false};
        case MotionSituation::Shake:
            return {"motion_annoyed", "shaken", LocalEffect::Annoyed, 2400, false};
        case MotionSituation::RepeatedShake:
            return {"motion_annoyed", "very annoyed", LocalEffect::Annoyed, 3600, false};
        case MotionSituation::DizzyAfterShake:
            return {"dizzy", "dizzy", LocalEffect::Dizzy, 3200, false};
        case MotionSituation::Rocking:
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

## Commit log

2026-09-08 Create circuit_diagram
2026-09-08 Add hardware photos, circuit diagrams and CAD files
    Wearable and desktop build photos, Fritzing exports for both units
    (png/svg/pdf plus the .fzz sources), and the OpenSCAD sources, printable
    STLs, renders and slicer profiles for the wearable enclosure. Includes
    the earlier Forearm_V1 revision alongside the final one.
    [Health_Companion.scad, Health_Companion_v1.scad, Kiki_Desktop.fzz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]
2026-09-08 Add live captures from the running system
    Redacted excerpts pulled from the Pi on 2026-09-08: the care plan
    (wearable telemetry, the fall alert chain, heart-rate readings with their
    signal-quality blocks, session outcomes), three journal entries, a live
    weather/AQI snapshot showing the CPCB calculation, and both test suite
    runs.
2026-09-08 Trim the asset folders
    Circuit diagrams keep the PNG of each board plus the two Fritzing
    sources; the SVG and PDF exports were the same drawings again.
    CAD keeps the OpenSCAD source, six renders and the single print plate.
    The slicer profiles, validation scripts, part-by-part STLs, variant
    enclosures and the V1 revision were internal working files.
    [Health_Companion.scad, Health_Companion_v1.scad, Shoe_Long_Side_Sensor_Contact.scad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]
2026-09-08 Put the photographs and the evidence up front
    Team photos open the write-up, then the two devices and the current
    numbers, before any prose. Four annotated figures added for the
    architecture, the single inference slot and the enclosure. Circuit
    diagrams, the gear train, the soldered board and the CAD renders now sit
    in the sections they belong to.
    Replaced the pointers to data/ with the data itself: the live AQI
    reading, the fall alert and its delivery outcome, the heart rate with its
    signal block, the CLIP observations in the vision model's own wording,
    how sessions actually ended, and both test runs.
2026-09-08 Add the source for both devices
    Working-tree snapshots of the two codebases, no git history imported.
    src/desktop-module the Raspberry Pi orchestrator
    src/wearable/firmware the ESP32-S3 firmware
    src/wearable/gateway the gateway both devices connect to
    Kept out: .env, gateway.env, config.json, the Vertex service-account key,
    sdkconfig, every built .bin, and all runtime state (transcripts, recorded
    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
    [partitions.csv]
2026-09-08 Add the analytics pipeline and the caregiver dashboard
    From AditiS721/SIH-Abnormalies-Software (branch DevAniket), included with
    the author's permission. src/health-analytics holds:
    src/ the rule-based pipeline — baseline, anomaly detection,
    daily summary, trend detection, risk score, JSON handoff
    esp32_export/ an Arduino sketch running the anomaly model on the board
    vitality-app/ the caregiver dashboard, Next.js with local SQLite
    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
2026-09-09 Add the earlier wheeled build and the desktop CAD render
    kiki-v1-wheeled.jpg is the pre-Kiki robot — Raspberry Pi, webcam, the
    black speaker, four wheels driven by remote. It is the only photograph
    of that build and it belongs with the pipeline history.
2026-09-10 Add system architecture documentation
    Document the system architecture and components for the wearable and desktop applications, including high-level flow and detailed descriptions of each component.
2026-09-10 Update README with prototype images
    Added images of the wearable and desktop prototypes to the README.
2026-09-10 Fix typo in image source for wearable prototype
2026-09-10 Clarify trust statement in README
    Rephrase trust statement for clarity and flow.
2026-09-10 Enhance README with system architecture diagram
    Added a mermaid diagram to illustrate system architecture and updated data flow explanations.

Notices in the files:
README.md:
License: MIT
